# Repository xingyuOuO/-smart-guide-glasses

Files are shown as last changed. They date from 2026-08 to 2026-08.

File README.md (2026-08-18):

專案封面

# Smart Guide Glasses (智慧視障導盲輔助眼鏡)





## 專案簡介
這是一個專為視障人士設計的輕量化穿戴式 AI 系統。本專案透過邊緣運算技術，在無網路的純離線狀態下進行影像辨識，並利用骨傳導技術將辨識結果與系統狀態（如電量警示）以語音播報給使用者，提供安全、即時且不干擾外界聽覺的環境感知輔助。

## 動機與背景
為了提供視障者更可靠的導引輔助，傳統依賴雲端運算的設備容易受網路延遲與無訊號死角的影響。因此，本專案致力於開發一款「純離線運作、硬體省電、且具備系統防錯機制」的邊緣運算裝置。同時，考量到聽覺對於視障者感知周遭環境的不可取代性，我們特別選用不遮蔽耳道的骨傳導發聲模塊，確保在傳遞系統語音提示的同時，使用者仍能清晰聽見外界的環境音。

## 功能特色
* **純離線 AI 影像辨識**：透過輕量化相機捕捉畫面，系統能在本地端進行高效率推論，辨識交通號誌（Traffic Label）等目標物，並即時回傳辨識分數與標籤。
* **骨傳導語音播報**：捨棄傳統喇叭，採用骨傳導模塊搭配高效率音訊放大晶片，播報預存於 Flash 中的輕量化語音（16kHz / 16-bit / Mono WAV 格式）。
* **多任務狀態機 (FSM) 架構**：系統內建穩定的狀態機設計，涵蓋「影像辨識」、「電壓檢測」與「聲音播放」三大核心狀態，能妥善處理定時電量檢查與高負載 AI 運算之間的排程衝突，防止系統阻塞卡死。
* **智慧電源管理與防錯**：開機即執行首檢與電壓檢測，並具備即時語音播報提醒；整體硬體與韌體經過省電優化，滿電狀態下續航力可達約 11 小時。
* **I2C 數據減量傳輸**：針對 AI 辨識結果，刻意捨棄繁重的座標資料 (x, y)，僅回傳輕量化的 JSON 格式標籤與信心度，大幅降低 I2C 通訊與主控板的資料處理負擔。

## 技術棧
* **主控與邊緣運算**：XIAO ESP32-S3
* **AI 推論與 NPU 部署框架**：SSCMA (Seeed Studio SenseCraft Master AI)
  > **技術亮點**：在此專案中，SSCMA 作為模型部署與神經網路處理（NPU 加速）的核心橋樑，負責將訓練好的 AI 模型最佳化並導入硬體中。它讓微型微控制器（MCU）也能具備足以應付視覺感知的邊緣運算能力，並透過 API (`AI.invoke()`, `AI.boxes()`) 輕鬆提取辨識結果。
* **相機模組**：OV5647
* **音訊放大晶片**：MAX98357A（採用 Class-D 高效率放大架構，轉換效率高達 92%）
* **通訊協定**：
  * **I2C**：用於鏡頭與主控板之間的 AI 辨識 JSON 數據通訊。
  * **I2S**：負責將 Flash 中的音訊檔案傳遞給放大晶片，並透過 LRC（左右聲道選擇）與 BCLK（位元時脈）確保時脈嚴格同步。
* **開發環境與語言**：C/C++, Arduino IDE (搭配 `<Seeed_Arduino_SSCMA.h>` 函式庫)

## 架構
**硬體佈線圖**
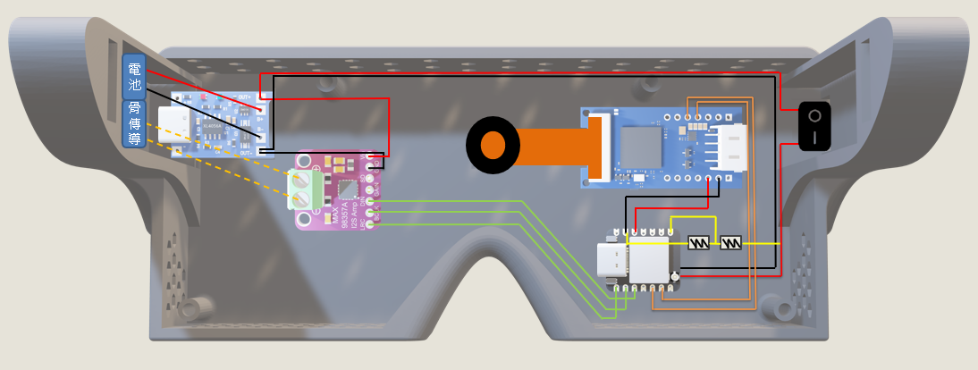
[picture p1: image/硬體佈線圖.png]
硬體佈線圖


**硬體架構圖**
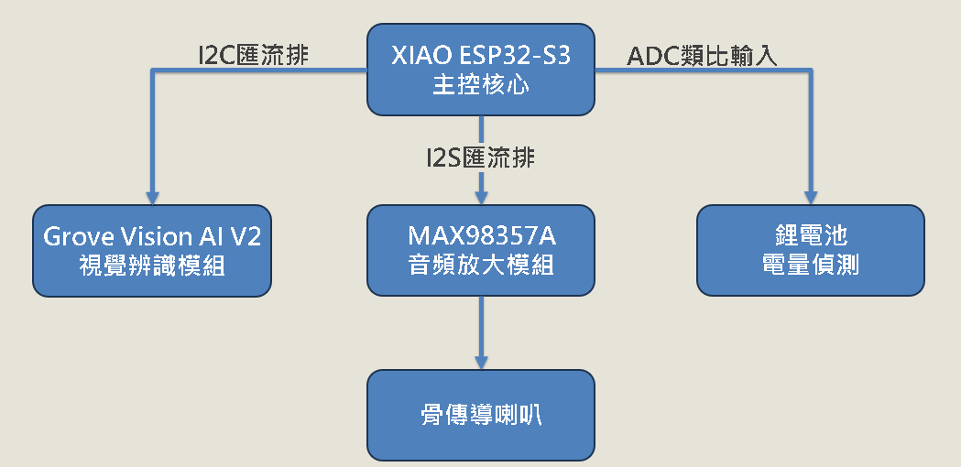
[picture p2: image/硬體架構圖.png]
硬體架構圖


**系統狀態圖**
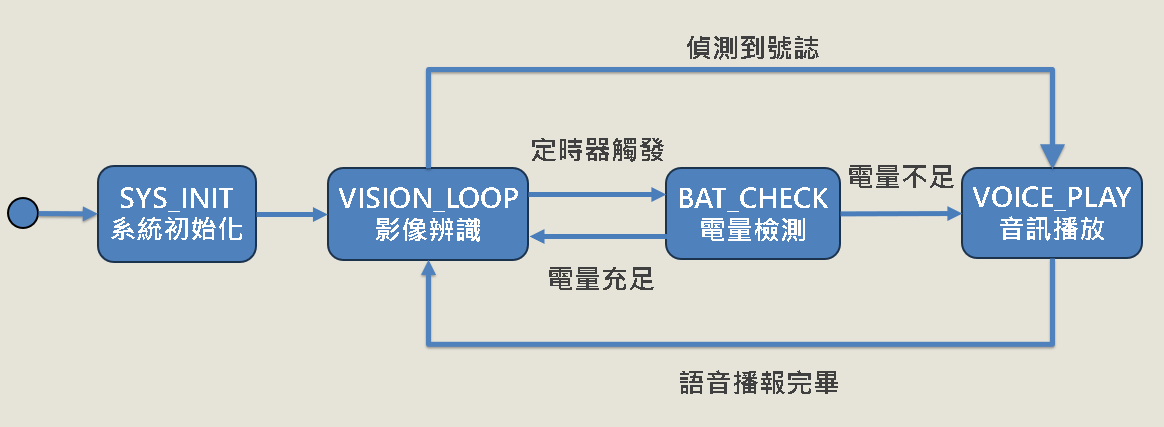
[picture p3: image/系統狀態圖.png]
系統狀態圖


## 專案結構
本系統核心以 **狀態機 (Finite State Machine)** 為基礎，確保資料流與控制流的穩定：
* `VISION_LOOP (視覺感知)`：負責驅動 OV5647 鏡頭捕捉畫面，觸發 SSCMA 進行 AI 推論，並透過 I2C 解析回傳的 JSON 辨識數據。
* `電壓檢測`：利用 ADC 採樣公式，定期換算並監控當前電池電量。
* `聲音播放`：透過 I2S 協定，從主機板 Flash 提取特定情境的 WAV 音檔，推播至 MAX98357A 進行放大與骨傳導發聲。

## 未來展望
* **擴充空間座標解析**：目前為了通訊數據減量，暫時捨棄了目標物在畫面中的 (x, y) 座標。未來若硬體效能允許，可評估將座標資訊加回，進階換算成實體空間方位，提供視障者更精確的「方向性」語音引導。
* **更細緻的排程與動態中斷**：針對更複雜的應用場景，可進一步優化 FSM 架構，引入多執行緒的動態中斷機制，讓危急警告（如極端低電量或突發危險障礙物）能更快速地插隊中斷當前的運作任務。

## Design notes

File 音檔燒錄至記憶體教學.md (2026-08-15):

# ESP32 語音播報 重點與步驟整理

---

## 一、重點整理

### 1. 兩個 IDE 分開使用

| IDE 版本 | 用途 |
| --- | --- |
| **Arduino IDE 1.8.19（舊版）** | 只用來上傳音檔（ESP32 Sketch Data Upload） |
| **Arduino IDE 2.x（新版）** | 寫程式、燒錄邏輯、看序列埠、除錯 |

### 2. 音檔規格

* 格式：**WAV**
* 取樣率：**16000 Hz**
* 聲道：**單聲道（Mono）**
* 位元深度：**16-bit PCM**
* ❌ 不要用 **MP3**（解碼太耗資源，可能沒聲音）
* ✅ 檔名建議用英文或數字，例如 `0001.wav`，不要有中文或空格

### 3. 沒聲音常見原因

* 音檔不是 16000Hz WAV 單聲道
* 檔名或路徑錯誤（程式裡要用 `/檔名.wav`）
* 音檔沒有實際上傳到 ESP32
* 上傳 data 時沒有關閉序列埠監視器
* 程式使用的檔案系統（SPIFFS / LittleFS）不一致

---

## 二、完整操作步驟

### 階段 A：準備音檔與 data 資料夾

1. **轉換音檔**：用 Audacity 或線上工具，設定 **16000Hz、單聲道**，匯出 **WAV（16-bit PCM）**
2. **命名音檔**：用簡單英文或數字，例如 `0001.wav`
3. **建立 data 資料夾**：在 `.ino` 檔案旁邊建立 `data` 資料夾，將 `.wav` 檔放入

資料夾結構：

```text
你的專案/
├── 你的專案.ino
└── data/
    └── 0001.wav
```

---

### 階段 B：用舊版 IDE 1.8.19 上傳音檔

1. **開啟 Arduino IDE 1.8.19**
2. 打開你的專案 `.ino` 檔
3. **關閉序列埠監視器**（重要，否則上傳會失敗）
4. 確認工具設定：

   * 開發板：正確的 ESP32 型號
   * 連接埠：正確的 COM Port
   * Flash Size / Partition Scheme：選擇有 **SPIFFS** 或 **LittleFS** 的分區
5. 點選 **「工具」→「ESP32 Sketch Data Upload」**
6. 等待進度條跑到 **100%**
7. 關閉舊版 IDE

> 如果工具選單沒有「ESP32 Sketch Data Upload」，表示尚未安裝 ESP32FS 外掛。

---

### 階段 C：用新版 IDE 2.x 修改程式並燒錄

1. 開啟 **Arduino IDE 2.x**
2. 打開同一個專案
3. 確認程式中有初始化檔案系統，例如：

   * `SPIFFS.begin(true);` 或 `LittleFS.begin(true);`
   * 以及音訊播放模組的初始化
4. 在對應的 `if` 判斷式內加入：

```cpp
playWav("/0001.wav");
```

* 路徑前面一定要有 `/`
* 檔名要和 `data` 資料夾內的檔名完全一致

5. 選擇正確的開發板與連接埠
6. 點擊上傳燒錄程式
7. 燒錄完成後，打開序列埠監視器測試

---

## 三、如果還是沒聲音，依序檢查

* [ ] 音檔是否為 **16000Hz、單聲道、WAV、16-bit PCM**
* [ ] 音檔是否放在 `data` 資料夾中
* [ ] 是否有用舊版 IDE 執行 **ESP32 Sketch Data Upload**
* [ ] 上傳 data 時是否已關閉序列埠監視器
* [ ] 程式中的路徑是否為 `/檔名.wav`
* [ ] 程式使用的檔案系統（SPIFFS / LittleFS）是否和上傳方式一致
* [ ] 音訊輸出硬體是否正確（DAC、I2S、功放、喇叭）
* [ ] 音量設定是否過小或未開啟

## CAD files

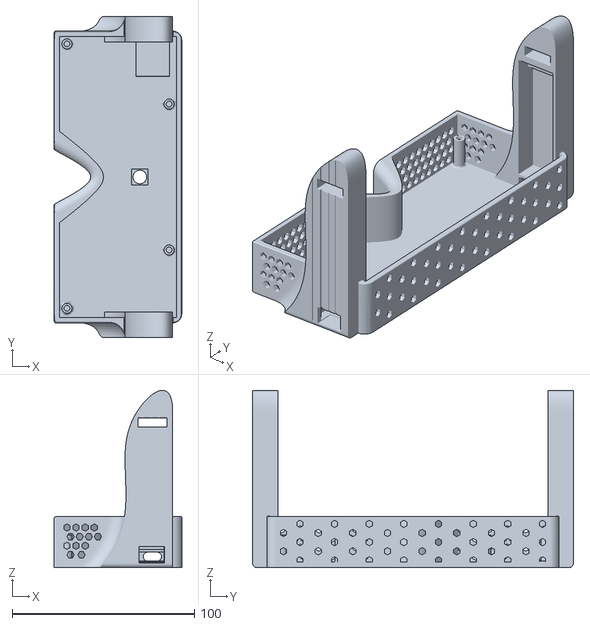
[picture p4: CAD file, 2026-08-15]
3D建模-眼鏡主體.stl
70.0 x 176.0 x 97.2

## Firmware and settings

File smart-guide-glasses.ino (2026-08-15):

#include <Arduino.h>
#include <Wire.h>
#include <FS.h>
#include <SPIFFS.h>
#include <driver/i2s.h>
#include <Seeed_Arduino_SSCMA.h>

// ============================================================
// 硬體設定
// ============================================================
#define I2S_LRC       1   // XIAO D0 -> MAX98357A LRC
#define I2S_BCLK      2   // XIAO D1 -> MAX98357A BCLK
#define I2S_DOUT      3   // XIAO D2 -> MAX98357A DIN
#define BAT_ADC_PIN   D3

// 必須和所有 WAV 音檔一致
#define AUDIO_SAMPLE_RATE 8000

#define CAMERA_ADDRESS  0x62
#define MIN_SCORE       25

SSCMA AI;

// ============================================================
// 系統狀態
// ============================================================
enum SystemState {
    SYS_INIT,
    VISION_LOOP,
    VOICE_PLAYBACK,
    BATTERY_CHECK
};

enum TrafficLabel {
    LIGHT_NULL  = -1,
    LIGHT_GREEN = 0,
    LIGHT_RED   = 1
};

enum AudioPrompt {
    PROMPT_NONE,
    PROMPT_GREEN,
    PROMPT_RED,
    PROMPT_BAT_MID,
    PROMPT_BAT_LOW
};

SystemState currentState = SYS_INIT;
TrafficLabel currentLabel = LIGHT_NULL;
TrafficLabel candidateLabel = LIGHT_NULL;
AudioPrompt pendingPrompt = PROMPT_NONE;

bool spiffsReady = false;
bool audioReady = false;
bool cameraReady = false;

int debounceCount = 0;
const int TH_DEBOUNCE = 5;

unsigned long lastBatCheck = 0;
const unsigned long BAT_INTERVAL = 900000;

unsigned long lastVoiceTime = 0;
const unsigned long VOICE_REPEAT_INTERVAL = 5000;

// ============================================================
// I2C 掃描
// ============================================================
bool scanI2C() {
    int count = 0;
    bool cameraFound = false;

    Serial.println("[I2C] 開始掃描...");

    for (uint8_t address = 1; address < 127; address++) {
        Wire.beginTransmission(address);
        uint8_t error = Wire.endTransmission();

        if (error == 0) {
            Serial.printf("[I2C] 發現裝置: 0x%02X\n", address);
            count++;

            if (address == CAMERA_ADDRESS) {
                cameraFound = true;
            }
        }
    }

    Serial.printf("[I2C] 共發現 %d 個裝置\n", count);

    if (!cameraFound) {
        Serial.println("[I2C] 警告：沒有找到 Grove 0x62");
    }

    return cameraFound;
}

// ============================================================
// I2S 初始化
// ============================================================
bool initI2S() {
    i2s_config_t config = {
        .mode = (i2s_mode_t)(I2S_MODE_MASTER | I2S_MODE_TX),
        .sample_rate = AUDIO_SAMPLE_RATE,
        .bits_per_sample = I2S_BITS_PER_SAMPLE_16BIT,
        .channel_format = I2S_CHANNEL_FMT_RIGHT_LEFT,
        .communication_format = I2S_COMM_FORMAT_STAND_I2S,
        .intr_alloc_flags = ESP_INTR_FLAG_LEVEL1,
        .dma_buf_count = 8,
        .dma_buf_len = 512,
        .use_apll = false,
        .tx_desc_auto_clear = true
    };

    i2s_pin_config_t pins = {
        .bck_io_num = I2S_BCLK,
        .ws_io_num = I2S_LRC,
        .data_out_num = I2S_DOUT,
        .data_in_num = I2S_PIN_NO_CHANGE
    };

    esp_err_t error =
        i2s_driver_install(I2S_NUM_0, &config, 0, nullptr);

    Serial.printf(
        "[I2S] driver install: %s (%d)\n",
        esp_err_to_name(error),
        error
    );

    if (error != ESP_OK) {
        return false;
    }

    error = i2s_set_pin(I2S_NUM_0, &pins);

    Serial.printf(
        "[I2S] set pin: %s (%d)\n",
        esp_err_to_name(error),
        error
    );

    if (error != ESP_OK) {
        i2s_driver_uninstall(I2S_NUM_0);
        return false;
    }

    i2s_zero_dma_buffer(I2S_NUM_0);

    Serial.println("[I2S] 初始化成功");
    return true;
}

// ============================================================
// WAV 播放
// ============================================================
bool playWav(const char *filename) {
    if (!audioReady) {
        Serial.println("[VOICE] I2S 尚未初始化，取消播放");
        return false;
    }

    if (!spiffsReady) {
        Serial.println("[VOICE] SPIFFS 尚未掛載，取消播放");
        return false;
    }

    if (!SPIFFS.exists(filename)) {
        Serial.printf("[VOICE] 找不到檔案: %s\n", filename);
        return false;
    }

    File file = SPIFFS.open(filename, "r");

    if (!file) {
        Serial.printf("[VOICE] 無法開啟檔案: %s\n", filename);
        return false;
    }

    if (file.size() <= 44) {
        Serial.printf("[VOICE] WAV 格式錯誤: %s\n", filename);
        file.close();
        return false;
    }

    Serial.printf(
        "[VOICE] 開始播放: %s，大小: %u bytes\n",
        filename,
        (unsigned int)file.size()
    );

    // 標準 PCM WAV header
    file.seek(44);

    uint8_t buffer[512];
    size_t bytesWritten = 0;
    bool success = true;

    while (file.available()) {
        int bytesRead = file.read(buffer, sizeof(buffer));

        if (bytesRead <= 0) {
            break;
        }

        esp_err_t error = i2s_write(
            I2S_NUM_0,
            buffer,
            bytesRead,
            &bytesWritten,
            portMAX_DELAY
        );

        if (error != ESP_OK ||
            bytesWritten != (size_t)bytesRead) {

            Serial.printf(
                "[VOICE] I2S 寫入失敗: %s，讀取=%d，寫入=%u\n",
                esp_err_to_name(error),
                bytesRead,
                (unsigned int)bytesWritten
            );

            success = false;
            break;
        }
    }

    file.close();

    // 送出靜音，清除尾音
    uint8_t zeroBuffer[512] = {0};

    for (int i = 0; i < 8; i++) {
        esp_err_t error = i2s_write(
            I2S_NUM_0,
            zeroBuffer,
            sizeof(zeroBuffer),
            &bytesWritten,
            portMAX_DELAY
        );

        if (error != ESP_OK) {
            Serial.printf(
                "[VOICE] 靜音資料寫入失敗: %s\n",
                esp_err_to_name(error)
            );

            success = false;
            break;
        }
    }

    i2s_zero_dma_buffer(I2S_NUM_0);

    Serial.printf(
        "[VOICE] 播放結果: %s\n",
        success ? "成功" : "失敗"
    );

    return success;
}

// ============================================================
// 視覺辨識
//
// 模型標籤：
// 0 = 綠燈
// 1 = 紅燈
// 2 = 黃燈，當成紅燈
// ============================================================
TrafficLabel getVisionResultFromI2C() {
    if (!cameraReady) {
        return LIGHT_NULL;
    }

    int result = AI.invoke();

    if (result != 0) {
        static unsigned long lastErrorTime = 0;

        if (millis() - lastErrorTime >= 3000) {
            Serial.printf(
                "[CAMERA] 推論失敗，錯誤碼: %d\n",
                result
            );

            lastErrorTime = millis();
        }

        return LIGHT_NULL;
    }

    const auto &boxes = AI.boxes();

    int bestGreenScore = 0;
    int bestRedLikeScore = 0;

    for (size_t i = 0; i < boxes.size(); i++) {
        int target = boxes[i].target;
        int score = boxes[i].score;

        // 0 = 綠燈
        if (target == 0 && score > bestGreenScore) {
            bestGreenScore = score;
        }

        // 1 = 紅燈，2 = 黃燈
        if ((target == 1 || target == 2) &&
            score > bestRedLikeScore) {
            bestRedLikeScore = score;
        }
    }

    // 安全優先：紅燈或黃燈優先
    if (bestRedLikeScore >= MIN_SCORE) {
        return LIGHT_RED;
    }

    if (bestGreenScore >= MIN_SCORE) {
        return LIGHT_GREEN;
    }

    return LIGHT_NULL;
}

// ============================================================
// 視覺去抖動
// ============================================================
void updateVisionPerception() {
    TrafficLabel detectedLabel =
        getVisionResultFromI2C();

    static unsigned long lastPrintTime = 0;

    if (millis() - lastPrintTime >= 1000) {
        if (!cameraReady) {
            Serial.println("[VISION] 相機尚未連線");
        } else if (detectedLabel == LIGHT_GREEN) {
            Serial.println("[VISION] 0 綠燈通行");
        } else if (detectedLabel == LIGHT_RED) {
            Serial.println("[VISION] 1/2 紅黃燈停止");
        } else {
            Serial.println("[VISION] 未偵測到有效號誌");
        }

        lastPrintTime = millis();
    }

    if (detectedLabel == LIGHT_NULL) {
        candidateLabel = LIGHT_NULL;
        debounceCount = 0;
        return;
    }

    // 新的候選燈號
    if (detectedLabel != currentLabel) {
        if (detectedLabel != candidateLabel) {
            candidateLabel = detectedLabel;
            debounceCount = 1;
        } else {
            debounceCount++;
        }

        if (debounceCount >= TH_DEBOUNCE) {
            currentLabel = candidateLabel;
            candidateLabel = LIGHT_NULL;
            debounceCount = 0;

            pendingPrompt =
                (currentLabel == LIGHT_GREEN)
                    ? PROMPT_GREEN
                    : PROMPT_RED;

            currentState = VOICE_PLAYBACK;
        }
    } else {
        candidateLabel = LIGHT_NULL;
        debounceCount = 0;

        if (millis() - lastVoiceTime >=
            VOICE_REPEAT_INTERVAL) {

            pendingPrompt =
                (currentLabel == LIGHT_GREEN)
                    ? PROMPT_GREEN
                    : PROMPT_RED;

            currentState = VOICE_PLAYBACK;
        }
    }
}

// ============================================================
// 電池電壓
// ============================================================
float getBatteryVoltage() {
    uint32_t sum = 0;

    for (int i = 0; i < 10; i++) {
        sum += analogRead(BAT_ADC_PIN);
        delayMicroseconds(50);
    }

    float average = sum / 10.0f;

    // 假設電池分壓比例為 1:1
    return (average / 4095.0f) * 3.3f * 2.0f;
}

void checkBatteryRoutine() {
    float voltage = getBatteryVoltage();

    Serial.printf(
        "[BATTERY] 電池電壓: %.2f V\n",
        voltage
    );

    if (voltage < 3.50f) {
        pendingPrompt = PROMPT_BAT_LOW;
        currentState = VOICE_PLAYBACK;
    } else if (voltage < 3.70f) {
        pendingPrompt = PROMPT_BAT_MID;
        currentState = VOICE_PLAYBACK;
    } else {
        currentState = VISION_LOOP;
    }
}

// ============================================================
// 初始化
// ============================================================
void setup() {
    Serial.begin(115200);
    delay(1500);

    Serial.println();
    Serial.println("====================================");
    Serial.println("智慧導盲眼鏡 - 穩定修正版");
    Serial.println("====================================");

    Wire.begin(D4, D5);
    Wire.setClock(100000);

    bool addressFound = scanI2C();

    analogReadResolution(12);

    // 相機只初始化一次
    if (addressFound) {
        Serial.println("[CAMERA] 開始初始化...");

        cameraReady = AI.begin(
            &Wire,
            -1,
            CAMERA_ADDRESS,
            2,
            100000
        );
    }

    if (cameraReady) {
        Serial.println("[CAMERA] 初始化成功");
    } else {
        Serial.println("[CAMERA] 初始化失敗");
    }

    // 掛載 SPIFFS
    spiffsReady = SPIFFS.begin(true);

    if (spiffsReady) {
        Serial.println("[SPIFFS] 掛載成功");
    } else {
        Serial.println("[SPIFFS] 掛載失敗");
    }

    // 初始化 I2S
    audioReady = initI2S();

    if (!audioReady) {
        Serial.println("[I2S] 音訊功能停用");
    }

    // 開機電量播報
    float bootVoltage = getBatteryVoltage();

    Serial.printf(
        "[BOOT] 開機電壓: %.2f V\n",
        bootVoltage
    );

    if (audioReady && spiffsReady) {
        if (bootVoltage < 3.50f) {
            playWav("/low.wav");
        } else {
            playWav("/mid.wav");
        }
    }

    lastBatCheck = millis();
    lastVoiceTime = millis();

    currentState = VISION_LOOP;
}

// ============================================================
// 主迴圈
// ============================================================
void loop() {
    switch (currentState) {
        case VISION_LOOP:
            updateVisionPerception();

            if (
                debounceCount == 0 &&
                millis() - lastBatCheck >= BAT_INTERVAL
            ) {
                currentState = BATTERY_CHECK;
            }
            break;

        case VOICE_PLAYBACK:
            switch (pendingPrompt) {
                case PROMPT_GREEN:
                    playWav("/green.wav");
                    break;

                case PROMPT_RED:
                    playWav("/red.wav");
                    break;

                case PROMPT_BAT_MID:
                    playWav("/mid.wav");
                    break;

                case PROMPT_BAT_LOW:
                    playWav("/low.wav");
                    break;

                default:
                    break;
            }

            if (
                pendingPrompt == PROMPT_GREEN ||
                pendingPrompt == PROMPT_RED
            ) {
                lastVoiceTime = millis();
            }

            pendingPrompt = PROMPT_NONE;
            currentState = VISION_LOOP;
            break;

        case BATTERY_CHECK:
            checkBatteryRoutine();
            lastBatCheck = millis();
            break;

        case SYS_INIT:
        default:
            currentState = VISION_LOOP;
            break;
    }
}

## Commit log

2026-08-15 第一次上傳專案(取消ppt檔案，檔案過大)
    [3D建模-眼鏡主體.stl]
2026-08-17 上傳架構圖及新增image資料夾
2026-08-18 壓縮封面gif
